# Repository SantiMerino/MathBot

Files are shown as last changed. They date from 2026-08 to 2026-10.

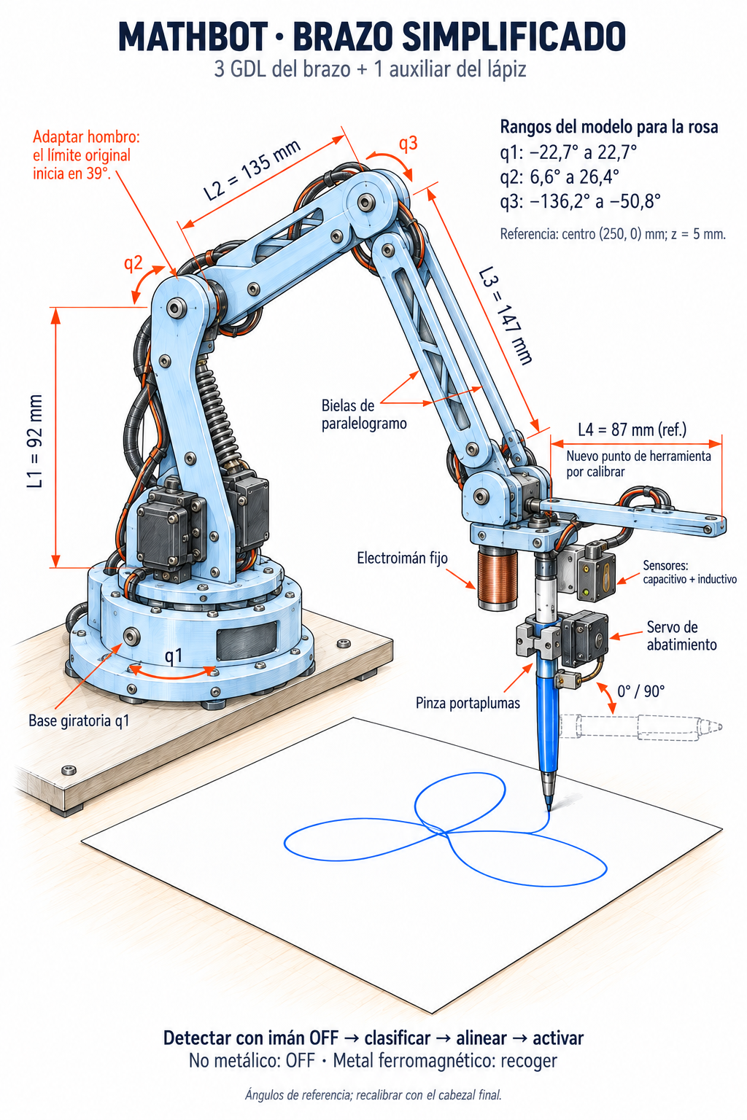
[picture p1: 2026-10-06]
Imagen de Codex 25 sept 2026, 07_56_44.png

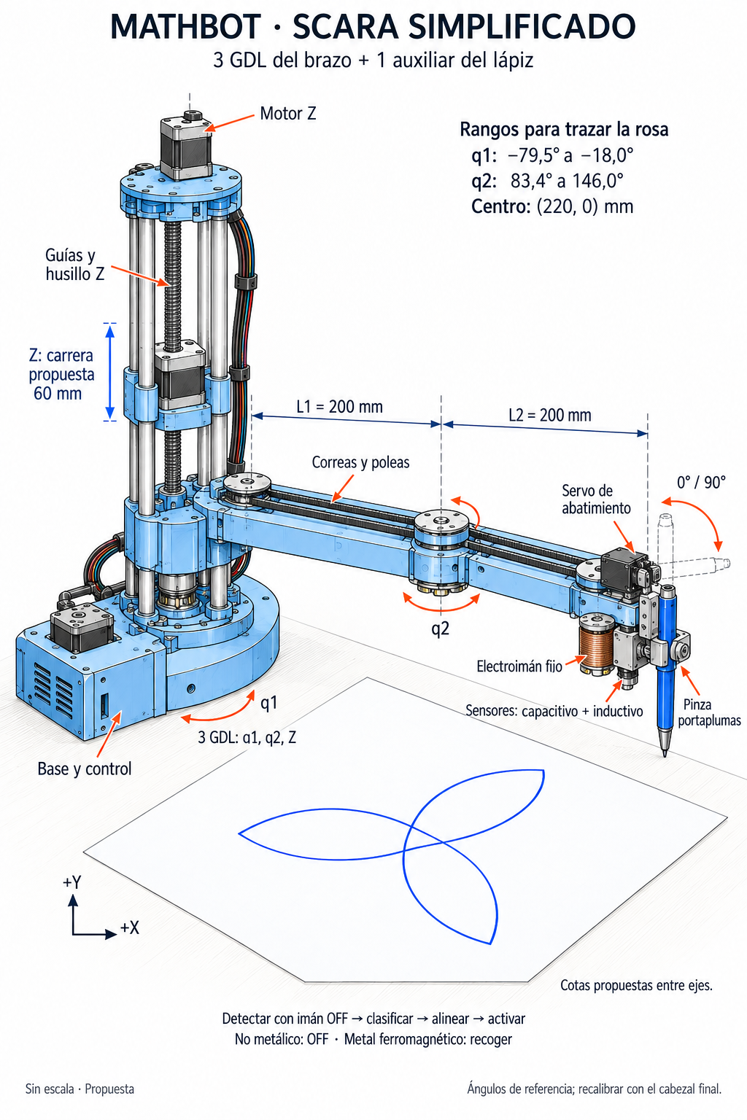
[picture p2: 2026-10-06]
Imagen de Codex 25 sept 2026, 07_56_58.png

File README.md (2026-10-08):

# MathBot

Brazo robótico de doble efector final — diseño, modelado y control de trayectorias matemáticas.

Proyecto de Aprendizaje Basado en Proyectos (PBL) que integra **Física Aplicada III** (20% del curso) y **Matemática Multivariable y Ecuaciones Diferenciales / Cálculo III** (15% del curso), semestre 2 de 2026.

---

## Pregunta retadora

> ¿Cómo podemos diseñar un brazo robótico de bajo costo capaz de manipular objetos mediante una pinza mecánica y un electroimán intercambiable, utilizando modelos matemáticos para generar y optimizar trayectorias que alcancen una precisión mínima del 90%?

## Descripción general

MATHBOT integra ambos cursos alrededor de un mismo producto físico: un brazo robótico de doble efector final, controlado por computador, capaz de ejecutar trayectorias matemáticas y realizar tareas de detección, recolección y manipulación de objetos.

A cada equipo se le entrega una **trayectoria física de referencia** construida en cartón (disponible en el SPARK). La primera tarea es observar y medir ese trazo, identificar sus características geométricas, y proponer y justificar una ecuación paramétrica —con dominio, orientación y escala— que la represente. El modelo se valida en MATLAB y, más adelante, se integra a una simulación 3D en Simulink del brazo real construido por el equipo.

---

## Nuestra trayectoria: rosa de tres pétalos

La referencia física asignada a este equipo es una **rosa de tres pétalos** con dos pétalos grandes (cuadrantes 1 y 4) y uno pequeño (eje X negativo).

### Ecuación paramétrica

$$x(t) = -A\cos(3t)\cos(t) \qquad y(t) = -A\,k\cos(3t)\sin(t) \qquad t \in [0,\pi]$$

con **A = 10.29 cm** y **k = 1.355**.

El parámetro `k` no es un ajuste arbitrario: la referencia física, tal como fue medida, parecía tener dos amplitudes distintas (13 cm en los pétalos grandes, 10 cm en el pequeño). Al medir directamente los píxeles del PDF de referencia, los tres pétalos resultaron **geométricamente idénticos** (682/680/680 px) — la asimetría aparente viene de que el documento coloca la imagen con una matriz de escala anisótropa (`sy/sx = 1.364`, confirmado por ajuste de mínimos cuadrados en `k = 1.355`). Es decir: **una sola ecuación con estiramiento en Y**, sin necesidad de una función definida por tramos.

> **Pendiente de validación física:** este modelo asume que el cartón del SPARK se imprimió a partir de ese PDF sin alteración de escala. Falta medir el trazo físico directamente y confirmar la razón pétalo-vertical / pétalo-horizontal ≈ 1.28.

### Discretización para el robot

La ejecución del brazo requiere convertir la curva continua en una lista finita de *waypoints*. El número de puntos se eligió por presupuesto de error, no de forma arbitraria:

- El objetivo de precisión del PBL es del 90% del **sistema completo**, no solo del modelo matemático. Fuentes de error ya presentes en un brazo de bajo costo: zona muerta del servo (4–9 mm), backlash de engranajes (2–5 mm), flexión de eslabones (1–4 mm), calibración del origen (2–5 mm).
- La discretización debe ser el término despreciable de esa suma → objetivo práctico: error de trazo **< 1 mm**.
- Con espaciado **adaptativo por curvatura** (más puntos donde el pétalo es más cerrado, cerca de la punta), **15 puntos por pétalo** (42 en la ruta completa) dan una desviación máxima de 0.56 mm respecto a la curva real — muy por debajo del presupuesto.

| Puntos/pétalo | Uniforme en t | Adaptativo |
|---|---|---|
| 10 | 2.14 mm | 1.37 mm |
| 12 | 1.43 mm | 0.91 mm |
| **15** | 0.93 mm | **0.56 mm** |
| 20 | 0.49 mm | 0.30 mm |

**Advertencia de implementación:** esta tabla asume que el robot interpola en línea recta entre waypoints en el plano X–Y. Si el control mueve los servos linealmente en *espacio articular* (ángulo a ángulo) en vez de cinemática inversa punto a punto, el camino cartesiano real se arquea entre waypoints y el error sube — en ese caso duplicar a 24–30 puntos por pétalo.

---

## Estructura del repositorio

```
MathBot/
├── README.md
├── docs/
│   └── MATHBOT_-_Semestre_2_2026.pdf     # enunciado oficial del PBL
├── modelo/
│   └── mathbot_trayectoria.html           # herramienta interactiva: modelo, error, export CSV/MATLAB/Arduino
├── mathbot_investigacion_construccion.html # investigación: arquitecturas, presupuesto de error, BOM y costos
├── mathbot_compras_el_salvador.html        # abastecimiento 100% local: tiendas, sustituciones, BOM en El Salvador
├── matlab/                                # simulación y validación (Avance 1 y 2)
└── firmware/                              # Arduino MEGA: firmware, pruebas, diagrama y Wokwi (ver firmware/README.md)
```

---

## Cómo se construye el brazo

`mathbot_investigacion_construccion.html` compara seis arquitecturas candidatas (antropomórfico,
SCARA, cartesiana/CNC, polar, delta y kit comercial) contra los requisitos del PBL, con presupuesto
de error, lista de materiales y costos.

**Conclusión:** SCARA de sobremesa de 3 GDL con cabezal de doble efector, eslabones `L₁ = L₂ = 20 cm`
y base a `D = 22 cm` del centro de la rosa. Con esa geometría, `θ₂` recorre solo el rango
`[72°, 126°]` en toda la trayectoria — lejos de ambas singularidades — y el número de condición
del jacobiano se mantiene por debajo de 3.5.

El hallazgo que decide el diseño no es geométrico sino de actuación: sobre esta configuración,
**1° de error articular se amplifica hasta 8.70 mm de error de trazo**. La zona muerta de un MG996R
es de 1–2°, así que en accionamiento directo el error de servo por sí solo consume todo el
presupuesto. La corrección es servo de bus serie con encóder (Feetech STS3215, 0.088° por cuenta →
0.77 mm) o reducción mecánica sobre servos analógicos.

| Ruta | Error de trazo | Costo total | Semanas |
|---|---|---|---|
| Económica — MG996R + reducción 3:1 | 4–6 mm | USD 175 | 5–6 |
| **Recomendada — SCARA + STS3215** | **≈ 2 mm** | **USD 305** | **7–9** |
| Alta precisión — NEMA 17 + AS5600 | 0.3 mm | USD 430 | 10–12 |

### Abastecimiento en El Salvador

`mathbot_compras_el_salvador.html` levanta el mapa de compras local (tiendas con dirección y
teléfono, qué comprar en cada una) y un árbol de decisión de cuatro rutas para el actuador, porque
no está confirmado qué hay realmente en el mostrador de Casa Rivas o Creativo 3D fuera de lo que
publican en línea.

| Ruta | Condición | Error | Precisión | Costo |
|---|---|---|---|---|
| A · servo de bus serie (STS3215) | si lo encuentran en stock | 1.99 mm | 98.5% | por cotizar |
| B · NEMA 17 + cabrestante 4:1 | si no hay bus serie pero sí stepper | 1.97 mm | 98.5% | ~243 USD |
| C · servo hobby + cabrestante | si no hay stepper pero sí cable de acero | 6.05 mm | 95.4% | 225 USD |
| D · servo hobby + engranes impresos | piso absoluto, cero compras extra | 6.65 mm | 94.9% | ~219 USD |

Las cuatro aprueban el 90% exigido. El hallazgo que no esperaba: con microstepping y una reducción
bien elegida, un NEMA 17 de mostrador (Ruta B) empata en precisión con un servo de bus serie que
cuesta el triple (Ruta A). La brecha real está entre {A, B} y {C, D}, no entre "importado" y
"local". Vale la pena llamar a Creativo 3D antes de resignarse a la Ruta C.

Los sensores y el electroimán sí tienen recomendación firme en cualquier ruta: fabricarlos en vez
de comprarlos. Un inductivo/capacitivo industrial local cuesta 25–60 USD cada uno; bobinarlos
cuesta ~5 USD y convierte el entregable de Física III en física medible, no en una hoja de datos.

La CNC (opción C del documento de construcción) sigue descartada: depende justo de la categoría
de piezas sin venta local confirmada. El brazo antropomórfico (opción A) sí es 100% local y usa la
misma canasta de compras que el SCARA, pero con servos directos el error va de 10 a 20 mm, rozando
el umbral.

---

## Simulación del SCARA de referencia (HowToMechatronics)

El diseño final toma como base el [SCARA de HowToMechatronics](https://howtomechatronics.com/projects/scara-robot-how-to-build-your-own-arduino-based-robot/)
(STL en `BRAZO SCARA/`). Medido en las STL: `L1 = 228 mm`, `L2 = 144 mm` (el código Arduino original
usa 136.5). J3 reduce 90/20 = 4.5:1. La pinza se reemplaza por uno de dos cabezales:

- **A · Disco tri-herramienta:** plumón a 55 mm hacia adelante (con J3 fijo actúa como un brazo 2 de
  199 mm), electroimán y sensor a 45 mm y ±120°; J3 gira para cambiar de herramienta. Varillas Z ≥ 240 mm
  (220 mm si J2 usa el NEMA 17 corto de 24 mm): el motor de J2 es lo que choca con la Top cover arriba.
- **B · Revólver triangular:** prisma 60 mm delante de J3 que un servo de 270° gira −120°/0°/+120° para
  dejar una cara hacia la hoja. Sin NEMA extra ni servo de levante, pero ≈90 g más y varillas Z ≥ 310 mm.

La rosa va centrada a 185 mm de J1, girada 180°: θ₂ ∈ [−140°, −96°], κ(J) ≤ 2.3, 0.19 mm por micropaso.
Qué imprimir y qué comprar para cada cabezal: [simulador_scara/CABEZALES_compras.md](simulador_scara/CABEZALES_compras.md).

- `simulador_scara/simulador_scara.html`: simulador 3D interactivo con las STL reales (abrir con doble
  clic; necesita internet para Three.js). Misión completa: escaneo con sensor → recolección con
  electroimán → trazo de la rosa, con cambio de cabezal A/B. Electrónica del artículo ubicada dentro
  de las piezas (motores, poleas, correas, rodamientos, Arduino + CNC Shield + A4988, finales de carrera),
  modo Rayos X e identificación de cada pieza con el cursor usando los nombres de HowToMechatronics.
  Se regenera con `python python/construir_simulador_scara.py` tras editar `plantilla.html`.
- `presupuesto/MathBot_Presupuesto_SCARA.xlsx`: presupuesto del robot con el cabezal de disco: lista de materiales con
  precios locales y de Amazon puestos en El Salvador, estado de compra, registro de gastos por integrante e impresión 3D.
  Se regenera con `python presupuesto/construir_presupuesto.py`.
- `presupuesto/rodamientos_scara.svg`: los 18 rodamientos (medidas, cantidad y dónde va cada uno), cotejados con el
  ensamble de HowToMechatronics. La lista de compras del artículo pide menos 51107/51108 y omite los radiales 6807/6806.
- `python/simular_scara.py [--gif] [--varilla 220]`: figuras para el informe (`python/figuras/scara_*.png`)
  y CSV con ángulos y pasos de motor por muestra.

---

## Cronograma de entregables — Cálculo III (15%)

| Entregable | Semana | Peso | Qué se evalúa |
|---|---|---|---|
| Avance 1 — Trayectoria paramétrica | 4 | 7% | Estimación/modelado, dominio y orientación, coherencia geométrica, justificación matemática, visualización en MATLAB, validación inicial contra la referencia física |
| Avance 2 — Optimización y simulación 3D | 12 | 3% | Actualización del modelo con restricciones de ingeniería, implementación en MATLAB/Simulink, simulación 3D del brazo real, informe técnico breve |
| Entrega final — Validación y defensa | 17 | 5% | Coherencia modelo–simulación–movimiento real, cuantificación y análisis del error, conclusiones, defensa oral |

## Cronograma de entregables — Física Aplicada III (20%)

| Entregable | Peso | Qué se evalúa |
|---|---|---|
| I. Propuesta conceptual y funcional básica | 5% | Bitácora de alternativas de materiales, arquitectura de control, grados de libertad, control individual y verificable de cada servomotor y del sensor de material |
| II. Control automático del robot | 15% | Ciclos estructurados de prueba, medición, análisis y ajuste; optimización del sistema físico y de control |

## Separación de evidencias por curso

| Evidencia | Curso | Enfoque |
|---|---|---|
| Ecuación paramétrica del trazo físico | Cálculo III | Modelado, justificación, dominio, orientación, visualización |
| Simulación 3D en Simulink | Cálculo III | Correspondencia geometría del prototipo ↔ modelo ↔ ejecución |
| Optimización y análisis de sensibilidad | Cálculo III | Herramientas de cálculo multivariable, restricciones, argumentación |
| Modelo con ecuaciones diferenciales | Cálculo III | Formulación, solución/interpretación, comportamiento dinámico |
| Estructura mecánica, servos, efectores | Física III | Diseño físico, viabilidad, carga, decisiones de ingeniería |
| Sensor de material, electroimán, circuitos | Física III | Principios eléctricos/magnéticos, pruebas, desempeño |
| Precisión final del recorrido | Ambas | Cálculo III: fidelidad matemática y error de trayectoria · Física III: desempeño físico y control |

---

## Requisitos funcionales del robot (Física III)

- Doble efector final: pinza mecánica + electroimán intercambiable.
- Sensor capaz de distinguir el tipo de material entre dos objetos desconocidos.
- Debe tomar únicamente el objeto **metálico de ~70 g** y desplazarlo por la trayectoria definida.
- Control individual y verificable de cada servomotor.

## Pendientes abiertos

- [ ] Medir el trazo físico en cartón (SPARK) y confirmar `k ≈ 1.355` contra la referencia real.
- [ ] Definir explícitamente el criterio de error (% del radio máximo, del radio local, o de la longitud de arco) para el reporte del 90% de precisión. *Propuesta en la investigación: `e_RMS ≤ 10% · R_max = 13.2 mm` como criterio oficial y `e_max < 3 mm` como meta interna. El criterio de radio local es inviable: la rosa pasa por el origen y la tolerancia se anula.*
- [ ] Decidir interpolación cartesiana vs. articular en el firmware, y ajustar el número de waypoints en consecuencia. *Propuesta: cartesiana — los servos de bus serie aceptan >50 Hz, suficiente para resolver la IK en línea.*
- [ ] Confirmar con el docente si el objeto metálico de 70 g es ferromagnético. Si es aluminio o cobre, el electroimán no lo levanta aunque el sensor inductivo sí lo detecte.
- [ ] Construir la simulación 3D en Simulink con la geometría real del prototipo (Avance 2).
- [ ] Documentar el diseño mecánico: grados de libertad, actuadores, arquitectura de control.

---

*Documento fuente: `MATHBOT_-_Semestre_2_2026.pdf`, enunciado oficial del PBL.*

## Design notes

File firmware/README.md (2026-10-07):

# Firmware MathBot · Arduino MEGA 2560

Diagrama de conexión

La CNC Shield V3 se monta sobre el Mega igual que sobre el UNO: los pines D2–D13 y A0–A3 coinciden,
así que motores y finales de carrera quedan como en el artículo de HowToMechatronics. Lo que agrega
el cabezal de disco va a los pines que solo tiene el Mega.

| Función | Pin | Notas |
|---|---|---|
| J1 · J2 · J3 · Z (STEP / DIR) | 2/5 · 3/6 · 4/7 · 12/13 | ranuras X, Y, Z, A (eje A clonado en D12/D13) |
| Enable de los 4 drivers | D8 | LOW = energizados |
| Finales SW1 J1 · SW2 J2 · SW3 J3 · SW4 Z | D11 · D10 · D9 · A3 | NC a GND, como HTM |
| Sensor inductivo (vía PC817) | D22 | LOW = metal |
| Electroimán (módulo MOSFET D4184) | D24 | diodo 1N5819 en paralelo a la bobina |
| START · PARO | D26 · D28 | NA a GND · hongo NC a GND |
| LED verde · amarillo · rojo | D30 · D32 · D34 | con 220 Ω |
| Buzzer | D36 | |
| Servo SG90 del plumón | D44 | alimentado por el buck a 5.5–6 V, no por el Mega |
| Monitor de 12 V | A8 | divisor 10 kΩ / 3.3 kΩ |
| Libres | Serial1–3, I2C 20/21, A9–A15, impares D23–D53 | HC-05, STS3215, AS5600, LCD |

Microstepping: jumper **solo en MS2** de cada driver (1/4 de paso, el que usa `python/scara_modelo.py`).

## Sketches

| Carpeta | Para qué |
|---|---|
| `mathbot_mega/` | Firmware completo: homing, IK por herramienta, cambio de herramienta con J3, misión (escaneo → recolección → rosa), paro de emergencia y comandos por Serial |
| `prueba_componentes/` | Menú para probar cada motor, final de carrera, sensor, electroimán, botones, LED, buzzer y los 12 V por separado |
| `prueba_servo/` | Calibra las posiciones ARRIBA/ABAJO del plumón; copia los valores a `SERVO_ARRIBA` / `SERVO_ABAJO` |

Necesitan la biblioteca **AccelStepper** (Gestor de bibliotecas). Placa: *Arduino Mega or Mega 2560*.
Monitor Serie a 115200 con fin de línea "Nueva línea".

Orden recomendado: `prueba_servo` → `prueba_componentes` (ajusta `INVERTIR_DIR` si un eje gira al revés)
→ `mathbot_mega` con `H` y luego `R`. Antes de la primera misión calibra `HOME_POS` (están los valores
de HTM) y las alturas Z.

## Simular en Wokwi

1. Abre <https://wokwi.com/projects/new/arduino-mega>.
2. Pestaña `diagram.json`: reemplaza todo por `wokwi/diagram.json`.
3. Library Manager → agrega **AccelStepper** (o crea `libraries.txt` con el de `wokwi/`).
4. Pestaña `sketch.ino`: pega el sketch que quieras probar y cambia `SIMULACION = true`
   (en Wokwi los finales de carrera son pulsadores NA).
5. Play. Comandos útiles en `mathbot_mega`: `S` (salta el homing), `?`, `T s`, `M 200 -100`, `D`, `R`.
   Para probar el homing con `H`, pulsa SW4, SW3, SW2 y SW1 en ese orden mientras cada motor gira.

En la simulación el electroimán es el LED morado, el sensor es el pulsador azul "Sensor: metal"
(mantenlo apretado durante el escaneo para marcar una pieza como metálica), el PARO es el interruptor
deslizante y el potenciómetro hace de divisor de 12 V. El servo se alimenta del 5 V solo en Wokwi.

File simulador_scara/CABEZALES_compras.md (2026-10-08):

# Cabezales MathBot: qué imprimir y qué comprar

Supuesto de materiales para los dos efectores que reemplazan la pinza del SCARA de HowToMechatronics.
El resto del robot (base, columna Z, brazos, poleas, NEMA 17, A4988, CNC Shield) se mantiene como en el artículo; el Arduino UNO se cambia por un MEGA 2560 (ver `firmware/README.md`).
Precios de referencia en USD (AliExpress / tiendas de electrónica); hay que confirmarlos en El Salvador.

## Comparación rápida

| | A · Disco tri-herramienta | B · Revólver triangular |
|---|---|---|
| Cómo cambia de herramienta | J3 gira ±120° | Servo de 270° gira el prisma −120° / 0° / +120° |
| Dónde queda la punta activa | 55 mm (plumón) / 45 mm del eje J3 | 60 mm delante de J3, en la línea del brazo 2 |
| Levante del plumón | Micro-servo SG90 (obligatorio) | No hace falta: el plumón sube con Z |
| Masa estimada | ≈ 150 g | ≈ 240 g |
| Varillas Z mínimas (NEMA de J2 estándar / corto 24 mm) | 240 / 220 mm | 310 / 300 mm |
| Principal fuente de error propia | Juego de la correa de J3 (≈0.5°) × 55 mm ≈ 0.5 mm | Zona muerta del servo (≈1°) × 85 mm ≈ 1.5 mm; con enclavamiento ≈ 0.2–0.3 mm |
| Tiempo de la misión simulada | 86 s | 101 s |

Ambos cumplen los tres requisitos (sensor de metales, electroimán y plumón/lápiz). La pinza original (servo MG996R + piezas) pesa unos 130–150 g, así que A queda igual y B suma unos 100 g.

## A · Disco tri-herramienta

**Imprimir** (≈ 50 g, ≈ 4.5 h)

| Pieza | Material | g | h |
|---|---|---:|---:|
| Placa-disco Ø136 × 6 mm (aligerada), 4 M4 al *Gripper to J3 connector* | PLA+/PETG, 3 perímetros, 30 % | 30 | 2.5 |
| Porta-plumón con camisa deslizante y resorte | PETG | 8 | 0.8 |
| Leva + soporte del micro-servo | PLA+ | 5 | 0.5 |
| Separador del electroimán (25 mm) | PLA+ o varilla M4 | 3 | 0.3 |
| Abrazadera M12 del sensor | PLA+ | 4 | 0.4 |

**Comprar**

| Componente | Cant. | USD | g |
|---|---:|---:|---:|
| Electroimán 12 V KK-P20/15 (Ø20 × 15, ≈2.5 kgf) | 1 | 3–5 | 32 |
| Sensor inductivo LJ12A3-4-Z/BX (M12, NPN NA, 4 mm) | 1 | 3–6 | 30 |
| Micro servo SG90 (o MG90S metálico) | 1 | 2–4 | 10 |
| Plumón Sharpie fino (o lápiz) | 1 | 1–2 | 11 |
| Resorte de compresión Ø10–12 × 20 mm | 1 | <1 | 1 |
| Tornillería M3/M4 + tuercas de seguridad | — | 2 | 10 |

## B · Revólver triangular

Prisma triangular en voladizo, 60 mm delante de J3 y con el eje a lo largo del brazo 2. La cara activa queda paralela a la hoja.
El voladizo no es un capricho: con 3 herramientas a 120° y un giro de 240°, dos de ellas pasan apuntando hacia arriba. Si el prisma colgara justo bajo J3, el sensor chocaría con el acople de J3. Por eso el plumón (la herramienta más larga) va en la posición central del servo y nunca apunta hacia arriba.

**Imprimir** (≈ 83 g, ≈ 8 h)

| Pieza | Material | g | h |
|---|---|---:|---:|
| Soporte en L (brida → 60 mm adelante) con mejilla para servo y rodamiento | PETG, 4 perímetros, 40 % | 30 | 3 |
| Prisma triangular hueco (lado 62 mm, largo 40 mm, eje Ø5) | PLA+/PETG, 30 % | 32 | 3 |
| Porta-plumón con resorte (cara 0°) | PETG | 8 | 0.8 |
| Base del electroimán (cara −120°) y boss M12 del sensor (cara +120°) | PLA+ | 7 | 0.7 |
| Acople horn del servo → prisma | PETG | 3 | 0.3 |
| Leva de 3 muescas (enclavamiento) | PETG | 3 | 0.3 |

**Comprar**

| Componente | Cant. | USD | g |
|---|---:|---:|---:|
| Servo 270° metálico DS3218MG (20 kg·cm), o MG996R + engranes impresos 2:3 | 1 | 10–15 | 60 |
| Rodamiento 625ZZ (5 × 16 × 5) + perno M5 × 50 | 1 | 1–2 | 8 |
| Émbolo de bola con resorte M6/M8 (o bola Ø5 + resorte) | 1 | 2–4 | 5 |
| Electroimán 12 V KK-P20/15 | 1 | 3–5 | 32 |
| Sensor inductivo LJ12A3-4-Z/BX | 1 | 3–6 | 30 |
| Sharpie Mini (o lápiz recortado ≈70 mm) | 1 | 1–2 | 7 |
| Resorte de compresión Ø10–12 × 20 mm | 1 | <1 | 1 |
| Tornillería M3/M4/M5 | — | 2 | 12 |

Par necesario: menos de 1 kg·cm (desbalance de herramientas + arrastre del plumón, 0.5 N × 85 mm). Cualquier servo de 270° alcanza; se pide uno metálico por rigidez y para reducir la zona muerta. No se usa otro NEMA.

## Electrónica común (A y B)

| Componente | Cant. | USD | Conexión |
|---|---:|---:|---|
| Módulo MOSFET de nivel lógico D4184 (o IRLZ44N) + diodo 1N5819 | 1 | 1–2 | electroimán → D24 |
| Optoacoplador PC817 (o divisor 10 kΩ / 4.7 kΩ) | 1 | 1 | sensor de 12 V → D22 |
| Convertidor buck 12 → 6 V: LM2596 (A) o XL4015 5 A (B) | 1 | 2–5 | alimenta el servo; señal en D44 |
| Cable flexible de 6–8 hilos AWG 24–26 (silicona), 1.5 m | 1 | 3–5 | pasa por los ejes huecos de J2 y J3 |
| Conectores JST-XH / Dupont y termorretráctil | — | 2 | — |

- Con el MEGA 2560 el cabezal usa pines que no toca la CNC Shield: **D22** sensor, **D24** electroimán y **D44** servo. Los finales de carrera siguen en D9, D10, D11 y A3, como en HTM.
- Diagrama completo y firmware en [`firmware/`](../firmware/README.md).
- **Fuente:** la de 12 V 6 A del artículo alcanza si el servo solo se mueve con los steppers quietos, como en la simulación.

El simulador (`simulador_scara.html`) muestra estas mismas tablas para el cabezal seleccionado.

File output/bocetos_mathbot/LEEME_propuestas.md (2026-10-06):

# MathBot: dos propuestas conceptuales
Fecha: 24 de septiembre de 2026.

Láminas elaboradas con image_gen integrado: propuesta_01_scara.png y propuesta_02_eezy.png. Los prompts y ajustes se conservan en prompts.md. Son bocetos de propuesta con despiece y BOM por conjuntos, sin escala ni tolerancias de fabricación. Las dimensiones del modelo y las dimensiones propuestas se distinguen a continuación.

## Requisitos y decisiones de diseño
Del enunciado MATHBOT_-_Semestre_2_2026.pdf: pinza mecánica y electroimán intercambiables, detección de material entre dos objetos desconocidos, selección únicamente del objeto metálico de aproximadamente 70 g, trayectoria matemática, control por computador/Arduino, control verificable de servomotores, sensor capacitivo, simulación del brazo real y objetivo de precisión mínima de 90%.

Solicitud adicional del usuario: dos bocetos, aspecto de lápiz/plano, identificación de piezas y cabezal modular automático con electroimán, sensor y Sharpie o lápiz. Se mantiene la pinza exigida por el proyecto.

Decisiones de estas propuestas: añadir detección inductiva complementaria al sensor capacitivo; bloqueo mecánico verificable; portaplumas con resorte; servos con encoder como candidatos. No son requisitos añadidos al enunciado ni selecciones comerciales definitivas. El sensor capacitivo se conserva en AMBAS propuestas aunque alguna anotación abreviada de la ilustración EEZY lo describa como opcional.

El sensor inductivo identifica presencia de metal bajo condiciones calibradas; no identifica por sí solo el tipo exacto de aleación. El electroimán requiere una pieza ferromagnética. Si el objeto metálico no es atraído, la pinza permite tomarlo después de la detección; no se debe programar la recolección del objeto no metálico. El sensor de bloqueo tiene otra función: verificar el acople o la posición del selector.

## Propuesta 01: SCARA con estación de intercambio
Inspiración mecánica: SCARA de HowToMechatronics. Conserva torre, guías verticales, husillo, carro y dos eslabones horizontales articulados. Adaptación: 2 rotaciones en XY y traslación Z; el cabezal reemplaza la garra original. Se proponen servos con encoder en las dos rotaciones, correas dentadas y motor de pasos en Z. La selección final de actuadores y sus transmisiones requiere cálculo de carga.

Geometría de partida de la investigación local: L1 = L2 = 200 mm y centro de rosa a D = 220 mm del eje de base. Son cotas propuestas de MathBot, no medidas copiadas del robot publicado. Longitudes de guías, recorrido Z, altura de papel y posición del almacén quedan por dimensionar.

Cambio automático: elevar; entrar en el puesto libre; apoyar el cartucho; retraer el pestillo; separar; ir a otra herramienta; centrar y acoplar; bloquear; confirmar; salir. Tres alojamientos: portaplumas, electroimán y pinza. Durante el uso de una herramienta su alojamiento queda vacío. La lámina ilustra el equipamiento de los tres puestos, no un inventario simultáneo de cartuchos.

El receptor permanece en el brazo con sensores y actuador de cierre. Cada cartucho lleva placa común, superficies de referencia, orientación mecánica y contactos eléctricos. El diseño debe descargar fuerzas en las superficies de apoyo, no en los contactos. Los contactos se energizan después de confirmar bloqueo y se desenergizan antes de liberar.

| ID | Pieza o conjunto | Cantidad preliminar | Desglose y función |
|---|---|---|---|
| 01 | Tablero de trabajo | 1 | Superficie plana, sujeción de papel y anclajes |
| 02 | Base y giro J1 | 1 conjunto | Carcasa, plato, eje y soporte de rodamientos |
| 03 | Servos con encoder | 2 | Movimiento de J1 y J2; soportes por diseñar |
| 04 | Guías verticales | 4 | Varillas y abrazaderas superior/inferior |
| 05 | Husillo T8 y tuerca | 1 conjunto | Husillo, tuerca, soporte axial |
| 06 | Motor Z y acople | 1 conjunto | Motor, soporte y acople al husillo |
| 07 | Carro y cojinetes lineales | 1 conjunto | Carro portabrazo y cojinetes correspondientes a las guías |
| 08 | Brazo 1 | 1 | Cuerpo, tapa y uniones; 200 mm entre ejes propuestos |
| 09 | Junta J2 y rodamientos | 1 conjunto | Eje, alojamiento, cojinetes y fijaciones |
| 10 | Brazo 2 | 1 | Cuerpo, tapa y soporte del receptor; 200 mm propuestos |
| 11 | Correas GT2, poleas y tensores | 2 juegos | Un juego por articulación; reducción por definir |
| 12 | Receptor y pestillo con servo | 1 conjunto | Brida, apoyo de centrado, llave antigiro, pestillo, servo, fin de carrera |
| 13 | Contactos y placas de herramienta | 1 juego | Bloque receptor de contactos y 3 placas/cartuchos compatibles |
| 14 | Sensores de material | 1 par | Sensor capacitivo y sensor inductivo auxiliar con soporte fijo |
| 15 | Portaplumas con resorte | 1 | Abrazadera, guía deslizante, resorte, tope y lápiz/Sharpie |
| 16 | Electroimán bobinado | 1 | Núcleo, bobina, carrete, aislamiento y placa |
| 17 | Pinza y microservo | 1 conjunto | 2 mordazas, transmisión, guías/ejes, servo y placa |
| 18 | Estación de tres puestos | 1 | Bastidor y 3 cunas con retención y referencias |
| 19 | Arduino, potencia y fuente | 1 conjunto | Controlador, interfaces, driver Z, reguladores y etapa del electroimán |
| 20 | Tornillos, insertos y cableado | 1 lote | Longitudes, calibres y cantidades por cerrar en CAD |

Ventaja conceptual: el brazo transporta solo el cartucho activo. Compromiso: necesita espacio para la estación y un acople repetible.

## Propuesta 02: EEZY con torreta modular
Inspiración: EEZYbotARM Mk2 y el modelo local easyEEZYbotARM. Conserva base giratoria, hombro, brazo/antebrazo y transmisión por bielas. Se propone estructura reforzada, soporte bilateral de articulaciones y compensación del peso del brazo mediante resorte.

La librería local define L1 = 92, L2 = 135, L3 = 147 y L4 = 87 mm. Son parámetros de referencia de la cadena original. El cabezal nuevo modifica la posición de la punta: L4 y el desplazamiento de cada herramienta necesitan actualización. La simulación local centra la rosa a X = 250 mm, utiliza Z = 5 mm y amplía los límites articulares del modelo; ello no demuestra contacto real con el papel ni ausencia de colisiones.

Selector automático: elevar a una zona despejada; liberar el bloqueo; girar el tambor a la siguiente estación nominal de 120 grados; bloquear y confirmar; compensar la posición de la herramienta; aproximar. Los tres cartuchos permanecen en el cabezal. Son desmontables para mantenimiento, pero la selección en servicio ocurre por giro del tambor. Un eje horizontal coloca un cartucho hacia abajo y los otros fuera del plano de trabajo. El sistema debe limitar el giro y retornar para evitar torsión acumulada del cableado.

| ID | Pieza o conjunto | Cantidad preliminar | Desglose y función |
|---|---|---|---|
| 01 | Tablero y base fija | 1 conjunto | Tablero, base y fijación |
| 02 | Plataforma giratoria J1 | 1 | Plato, apoyo y eje |
| 03 | Servos con encoder | 3 | Base, hombro y accionamiento de codo/bielas |
| 04 | Soportes de hombro | 1 par | Placas laterales con apoyo bilateral |
| 05 | Brazo superior | 1 | Eslabón y fijaciones |
| 06 | Antebrazo | 1 | Eslabón distal y fijaciones |
| 07 | Bielas de paralelogramo | 1 juego | Barras, pivotes y articulaciones de transmisión/nivelación |
| 08 | Ejes, cojinetes y separadores | 1 lote | Uniones de base, brazo y transmisión |
| 09 | Resorte de compensación | 1 | Resorte y dos anclajes; precarga por calcular |
| 10 | Portacabezal nivelado | 1 | Soporte del conjunto distal |
| 11 | Horquilla de torreta | 1 | Dos apoyos del eje y unión al portacabezal |
| 12 | Tambor y eje horizontal | 1 conjunto | Tambor de 3 estaciones, eje y dos rodamientos |
| 13 | Servo selector | 1 | Accionamiento del tambor; transmisión por dimensionar |
| 14 | Indexador, bloqueo y sensor | 1 conjunto | Disco, pasador, liberación actuada y confirmación de posición |
| 15 | Cartucho de lápiz con resorte | 1 | Placa, abrazadera, guía, resorte y herramienta |
| 16 | Cartucho de electroimán | 1 | Placa, núcleo, bobina y conexiones |
| 17 | Cartucho de pinza y microservo | 1 | Placa, mordazas, ejes/transmisión y microservo |
| 18 | Sensores capacitivo e inductivo | 1 par | Soporte fijo fuera del barrido del tambor |
| 19 | Arduino, potencia y fuente | 1 conjunto | Control, interfaces de servos/sensores y etapa de potencia |
| 20 | Tornillos, insertos y cableado | 1 lote | Incluye conectores de cartucho y lazo de cable de giro limitado |

Ventaja conceptual: selección sin estación externa. Compromiso: el brazo soporta todos los cartuchos, el tambor y su accionamiento. Los 70 g corresponden al objeto y se suman al peso completo del cabezal; no se ha validado la capacidad del EEZY modificado.

## Electrónica común y validaciones necesarias
- PC/MATLAB o Python envía trayectorias al controlador. La geometría final deberá trasladarse a Simulink conforme al enunciado.
- Alimentación de actuadores dimensionada por corrientes reales; regulación independiente para lógica/sensores según componentes elegidos.
- Electroimán controlado mediante etapa MOSFET y diodo de rueda libre; adaptar las señales de sensores a la tensión lógica.
- Comprobar bloqueo y herramienta seleccionada antes de ejecutar la trayectoria.
- Calibrar el punto de trabajo de cada herramienta y la altura del papel. La punta de escritura requiere recorrido elástico y fuerza de contacto limitada.
- Verificar par, rigidez, carga con herramienta, holgura, repetibilidad, interferencias, alcance de toda la rosa y acceso al almacén o barrido de torreta.
- Definir con el curso la métrica del 90% y medirla en el robot físico. Ni estos bocetos ni la coincidencia IK/FK prueban esa precisión.
- Tornillos e insertos aparecen como lote porque faltan CAD, espesores y tolerancias. No se trasladan automáticamente las medidas M3/M4 de la imagen original a los nuevos cabezales.

## Fuentes consultadas
- [SCARA de HowToMechatronics](https://howtomechatronics.com/projects/scara-robot-how-to-build-your-own-arduino-based-robot/): arquitectura, guías, transmisiones y montaje de referencia.
- [easyEEZYbotARM](https://github.com/meisben/easyEEZYbotARM): modelo y documentación del brazo. Sus notas de uso no acreditan una capacidad de 70 g para esta adaptación.
- [EEZYbotARM Mk2, autor original](https://www.instructables.com/EEZYbotARM-Mk2-3D-Printed-Robot/).
- Enunciado local: MATHBOT_-_Semestre_2_2026.pdf.
- README.md y mathbot_investigacion_construccion.html: trayectoria y geometría SCARA propuesta. Sus estimaciones de desempeño/costos no se consideran resultados experimentales.
- python/easyEEZYbotARM/kinematic_model.py: dimensiones originales Mk2.
- python/simular_trayectoria_eezy.py y python/figuras/eezy_poses_petalos.png: configuración y vistas de la simulación local.

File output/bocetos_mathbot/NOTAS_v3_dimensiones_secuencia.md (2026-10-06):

# MathBot v3: cabezal sencillo, dimensiones y ángulos
Fecha: 24-09-2026. Dibujos generados con ImageGen; sin escala y sin tolerancias de fabricación. Esta revisión sustituye la propuesta de torreta/cambio automático para la función solicitada. No modifica las simulaciones ni los documentos anteriores.

## Función del cabezal
Una placa fija porta el electroimán y los sensores. Una pinza sencilla de dos mitades sujeta exclusivamente el lápiz; se aprieta manualmente. Un servo auxiliar abate el portaplumas: posición nominal 0° para escribir y 90° para retirarlo. Son posiciones funcionales propuestas, no pulsos ni ángulos absolutos del servo seleccionado.

No hay almacén, cartuchos intercambiables, torreta ni apertura/cierre motorizado de la pinza. El electroimán recoge objetos; la pinza sostiene el instrumento que traza la curva. El lápiz, electroimán y sensores están lateralmente separados, nunca apilados en el mismo eje. El lápiz desplegado llega al papel antes que el imán; al abatirlo, el imán queda libre para aproximarse al objeto. El muelle/guía del portaplumas, los topes de abatimiento y su despeje deben dimensionarse con el lápiz real.

## Dimensiones y grados de libertad
| Parámetro | SCARA | Brazo EEZY |
|---|---|---|
| Primer eslabón móvil | 200 mm entre ejes | L2 = 135 mm, hombro a codo |
| Segundo eslabón móvil | 200 mm entre ejes | L3 = 147 mm, codo a muñeca |
| Desplazamiento vertical fijo | Según montaje de torre | L1 = 92 mm, referencia base a hombro del modelo |
| Desplazamiento de herramienta original | Modelo XY de dos barras | L4 = 87 mm, desplazamiento horizontal original, no longitud del lápiz |
| Eje vertical | Carrera propuesta 60 mm | Movimiento combinado de hombro/codo |
| GDL de posicionamiento | 3: q1, q2, Z | 3: q1, q2, q3 |
| Movimiento auxiliar independiente | 1: abatimiento de lápiz | 1: abatimiento de lápiz |

Por tanto, cada propuesta tiene cuatro movimientos actuados independientes contando el portaplumas. El electroimán ON/OFF no añade un grado de libertad. La pinza apretada no añade otro eje controlado. Las bielas pasivas tampoco son GDL adicionales.

Dimensiones de bielas auxiliares que figuran en la librería EEZY: L2A = 60 mm, LAB = 140 mm y LB3 = 60 mm. Son parámetros de su mecanismo original, no cotas de cualquier barra visualmente parecida del boceto. Conservar su conectividad y validar nivelación en CAD. Las láminas solo acotan la cadena principal para mantener legibilidad.

## Ángulos: cálculo, convenciones y alcance
Se evaluaron 20 001 muestras de:
x_r = -102.9 cos(3t) cos(t), y_r = -102.9 × 1.3552 cos(3t) sin(t), t de 0 a pi.
Todas las longitudes se expresan en mm. La rosa tiene un pétalo hacia -X.

| Articulación | SCARA: centro (220,0) | EEZY original: centro (250,0), z=5 |
|---|---:|---:|
| q1 | -79.467° a -17.963° | -22.696° a 22.696° |
| q2 | 83.419° a 145.955° | 6.577° a 26.388° |
| q3 | No aplica | -136.213° a -50.766° |

Estos son intervalos articulares requeridos por la curva del MODELO DE REFERENCIA, no límites garantizados del mecanismo ni recorridos de servomotores. La ilustración es una vista de conjunto, no una pose numérica determinada.

SCARA: q1 se mide desde +X hacia el primer eslabón; q2 es el giro relativo del segundo respecto al primero. Se utiliza la rama q2 positiva. La orientación completa de la placa distal cambia con q1+q2, por lo que el desplazamiento lateral entre lápiz, sensor e imán debe rotarse al compensarlo.

EEZY: q1 es el giro de base desde +X; q2, la elevación del primer eslabón móvil desde la horizontal; q3, el giro relativo del codo. La elevación absoluta del antebrazo es q2+q3. Los ángulos del modelo no equivalen directamente a los comandos de servo: la librería los transforma mediante calibración y geometría de bielas.

El cálculo reproduce la cinemática directa con error numérico inferior a 1e-8 mm. Esto solo verifica las ecuaciones, no la precisión del robot.

### Diferencia con cifras previas del SCARA
El rango de codo 72° a 126° del documento anterior corresponde al alejamiento del pétalo pequeño respecto a la base, una orientación diferente de la usada aquí. Con la ecuación negativa del README y el centro en (220,0), el rango correcto es 83.4° a 146.0°. Cambiar orientación o ubicación de la curva exige recalcular ambos ángulos.

### Restricción real del EEZY
El modelo original establece q1 entre -30° y 30°, q2 entre 39° y 120°, y límites de q3 dependientes de q2:
q3_min = -0.6755 q2 - 70.768;
q3_max = -0.7165 q2 - 13.144.
La trayectoria actual requiere q2 inferior a 39° en todas las muestras: no cabe en esos límites originales.

La simulación local amplía q2 a 0°–120° y q3 a -160°–-20°. Ampliar esos números no modifica los topes físicos ni demuestra ausencia de colisión. El EEZY requiere adaptar montaje/geometría o reubicar el plano de dibujo y volver a calcular la trayectoria.

El nuevo cabezal introduce desplazamientos horizontales y verticales distintos para lápiz, sensor e imán; L4=87 mm y z=5 mm son referencias del modelo anterior. En particular, z=5 mm no representa automáticamente contacto real con el papel. Hay que medir las tres posiciones de trabajo y actualizar la cinemática antes de usar los rangos como diseño definitivo.

## Secuencia de detección y recogida
1. Elevar el cabezal y abatir el lápiz a la posición retirada; mantener el imán apagado.
2. Situar los sensores frente al objeto a la distancia de detección calibrada, con sus campos despejados del imán y la estructura.
3. Confirmar presencia mediante el capacitivo y comprobar respuesta del inductivo. Solo clasificar tras lecturas estables en una región y distancia donde ambos sensores hayan sido caracterizados.
4. Si hay presencia y no respuesta inductiva, clasificar provisionalmente como no metálico dentro de esa calibración y no activar el imán. Si no se confirma presencia, repetir aproximación; una lectura negativa sola no prueba material no metálico.
5. Si se confirma metal, guardar la clasificación, elevar y desplazar la herramienta para alinear el electroimán sobre el mismo objeto. Compensar la separación física sensor–imán con la orientación actual del brazo.
6. Bajar, activar el imán mediante etapa de potencia y realizar una elevación corta de comprobación. Solo transportar si se verifica recogida; la detección inductiva no confirma por sí misma que la pieza quedó sujeta.
7. Depositar y desactivar. Antes de otra detección, esperar la estabilización del sistema y volver a leer con el imán apagado.
8. Para dibujar: imán apagado, desplegar lápiz, ajustar contacto y ejecutar la rosa.

El capacitivo detecta tanto materiales metálicos como no metálicos; no garantiza clasificación de objetos desconocidos por sí solo. Se propone el inductivo como complemento. La clasificación depende de tamaño, distancia y material, y requiere ensayos con las piezas reales.

Un metal detectado puede no ser ferromagnético: aluminio/cobre pueden detectarse pero no levantarse con este electroimán. La secuencia de recogida presupone una pieza ferromagnética; ante falta de sujeción, detener/rechazar, sin utilizar la pinza del lápiz como garra. El sensor y el imán funcionan en una misma secuencia, sin exigir detección fiable mientras el imán está energizado.

## Pendientes de dimensionamiento
- Masa completa del cabezal más objeto de unos 70 g, par de cada articulación, retención magnética real y calentamiento de bobina.
- Soporte del servo de abatimiento con tope mecánico para que el juego del servo no determine por sí solo la posición de escritura.
- Calibración y montaje de sensores para evitar detectar permanentemente el propio núcleo, tornillos o soporte.
- Transistores/driver, protección de carga inductiva y alimentación compatibles con bobina y sensores.
- Recorridos físicos con margen, altura de objetos, evitación de colisiones y postura para abatir el lápiz.
- Criterio de precisión del 90% y ensayo experimental. No se acredita con este boceto.

## Archivos y fuentes
- scara_vertical_cotas_v3.png y brazo_vertical_cotas_v3.png: láminas finales.
- verificar_angulos_v3.py y angulos_referencia_v3.json: cálculo reproducible y resultados.
- prompts_v3_dimensiones.md: prompts de generación y correcciones.
- python/easyEEZYbotARM/kinematic_model.py: cotas, límites y convenciones originales.
- python/simular_trayectoria_eezy.py: curva, centro, altura y límites ampliados.
- README.md y mathbot_investigacion_construccion.html: geometría propuesta y requisitos.
- [ifm: sensores capacitivos y diferencia con inductivos](https://www.ifm.com/us/en/category/200_010_030).
- [ifm: alcance y respuesta de sensores inductivos](https://www.ifm.com/us/en/us/overview/inductive/technology-overview/tech-overview).

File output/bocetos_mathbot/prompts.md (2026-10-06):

# Prompts finales

## Ajuste de la segunda lámina: torreta y numeración

Edit this existing MathBot EEZY technical proposal sheet. Preserve the pencil/blue/orange style, title, main EEZY robot body and linkage, reference dimensions, overall layout, sensor pair, and 3-petal curve. Correct the turret depiction and replace the corrupted bottom BOM strip. This is a mechanical-clarity correction, not a redesign.
1. In both main robot's head and enlarged operational head, render a drum rotating on a HORIZONTAL axle, with exactly THREE tool cartridges attached RADIALLY 120 degrees apart in the same rotational plane. The active pen cartridge projects straight DOWN from the bottom radial face. The magnet cartridge projects UP-LEFT from another radial face with its pole face pointing up-left. The gripper cartridge projects UP-RIGHT from the third radial face with jaws pointing up-right. Thus only the pen can touch the paper; the tools are not all hanging parallel vertically. Draw radial support mounts explicitly. Keep fixed two-sensor bracket on stationary outer yoke pointing down, separated from rotating envelope. Horizontal-axis motor drive and bearings connect to side of drum, not a top vertical spindle. Exploded detail corresponds to this same architecture, with three cartridges shown around drum radially using dashed assembly arrows, not stacked inline on shaft. Tool pose clarity is the most important visual change.
2. Replace entire bottom illustrated BOM strip with a CLEAN LEGIBLE TABLE of 20 exact rows split into 2 column groups (01–10 left, 11–20 right). No duplicate IDs. Table contents verbatim:
01 Tablero y base fija | 1 conj.
02 Plataforma giratoria J1 | 1
03 Servos con encoder | 3
04 Soportes de hombro | 1 par
05 Brazo superior | 1
06 Antebrazo | 1
07 Bielas de paralelogramo | 1 juego
08 Ejes, cojinetes y separadores | 1 lote
09 Resorte de compensación | 1
10 Portacabezal nivelado | 1
11 Horquilla de torreta | 1
12 Tambor y eje horizontal | 1 conj.
13 Servo selector | 1
14 Indexador, bloqueo y sensor | 1 conj.
15 Cartucho de lápiz con resorte | 1
16 Cartucho de electroimán | 1
17 Cartucho de pinza y microservo | 1
18 Sensores capacitivo + inductivo | 1 par
19 Arduino, potencia y fuente | 1 conj.
20 Tornillos, insertos y cableado | 1 lote
Allocate sufficient height to table, shrinking the operational drawing only if necessary.
3. Footer date 24-09-2026, add concise footer "70 g: objetivo por validar. Electroimán para ferromagnéticos." Keep "PROPUESTA CONCEPTUAL · SIN ESCALA · BOM PRELIMINAR".
4. Correct main arm balloons: 05 points upper arm from shoulder to elbow, 06 points forearm from elbow to wrist, 07 points slender linkage. The base servo is J1, shoulder J2, elbow drive J3.
Keep all typography in Spanish, no invented specs, no accuracy claims.

## Ajuste final del BOM de la segunda lámina

Edit ONLY the bottom BOM table strip in this image, preserving absolutely every other image region, drawing, labels, title, footer and style pixel for pixel. The table contains duplicated/missing numbers and incorrect labels. Replace that strip with four equal width tables next to each other, five data rows per table, each having three columns "N°", "Pieza", "Cant.". No illustrations in the strip. Draw ample room and type crisp small dark text. Do not attempt 10 rows in the short strip. Four blocks of exactly five rows as follows:
BLOCK ONE, IDs 01-05:
01 | Tablero y base fija | 1 conj.
02 | Plataforma J1 | 1
03 | Servos con encoder | 3
04 | Soportes de hombro | 1 par
05 | Brazo superior | 1
BLOCK TWO, IDs 06-10:
06 | Antebrazo | 1
07 | Bielas | 1 juego
08 | Ejes y cojinetes | 1 lote
09 | Resorte | 1
10 | Portacabezal | 1
BLOCK THREE, IDs 11-15:
11 | Horquilla | 1
12 | Tambor y eje | 1 conj.
13 | Servo selector | 1
14 | Bloqueo y sensor | 1 conj.
15 | Cartucho de lápiz | 1
BLOCK FOUR, IDs 16-20:
16 | Electroimán | 1
17 | Pinza y microservo | 1
18 | Sensores de material | 1 par
19 | Control y fuente | 1 conj.
20 | Tornillos y cableado | 1 lote
Each number 01 through 20 appears exactly once in this table. Do not merge rows. Do not repeat groups. Keep heading "LISTA DE MATERIALES (BOM PRELIMINAR)". Preserve date and conceptual footer.

Herramienta: image_gen integrada, dos generaciones independientes.

## Propuesta 01

Use case: infographic-diagram. Create a polished engineering proposal sheet for a university MathBot, in SPANISH. Wide landscape 3:2, very high resolution, ideally 3840 pixels wide. White warm drafting paper, graphite pencil outlines and crosshatching, faint construction lines, restrained pale blue mechanical panels, orange-red thin leaders and numbered balloons. Not a photorealistic render. Legible carefully typeset technical Spanish labels, clean generous whitespace, no labels crossing objects. A cohesive professional pencil technical drawing like an exploded assembly drawing, with full robot clearly visible. Main assembled perspective 55% left; exploded mechanism detail upper right; numbered illustrated parts layout and compact BOM lower strip/right. All parts numbered consistently. Include a drawing title block and clearly write "PROPUESTA CONCEPTUAL · SIN ESCALA · BOM PRELIMINAR". Do not claim manufacturing-ready dimensions, guaranteed accuracy, proven payload, or source model compatibility. Show the actual MathBot three-petal rose drawn in blue on paper on the table (one petal toward left, two toward upper/lower right), a metal test object labelled "70 g · objetivo de carga", and a separate nonmetal test object. End effector includes capacitive plus auxiliary inductive material sensing, electromagnet, a pen/pencil module, and mechanical gripper. Detection of material is distinct from tool-position sensing. A ballpoint/Sharpie held vertically, with spring compliant holder, traces the rose. The magnet is a wound coil on iron core, clearly NOT a suction cup. The mechanical gripper is two jaws, with small dedicated servo. Sensors point toward the target, not toward another metal tool. Tool exchange or selection happens lifted above the sheet. All cables have plausible routing. Keep the board beautiful, detailed and physically intelligible.
TITLE exactly: "MATHBOT / 01 — SCARA CON CAMBIO AUTOMÁTICO".
Input image 1 is a mechanical architecture and annotation reference only: HowToMechatronics blue SCARA with tall rod tower and two horizontal belt-driven arms. Create a NEW drawing adapting it, not copying its gripper. Retain recognisable base, 4 vertical guide rods, lead screw, sliding carriage, two horizontal articulated links, bearing-supported rotary joints and GT2 belts with tensioners; adapt to two planar joints plus Z, omit original rotary wrist. Main illustration has one pen module attached; rack holds the magnet and gripper modules plus one empty pen bay. TWO horizontal arm links each nominal 200 mm center-to-center, dimension arrows marked "200 mm · propuesta". Show small plan inset with "Centro de rosa: D = 220 mm" from base axis, not the outer board dimension. Four smooth rods and one central T8 lead screw raise both arm links on their carriage. Actuation proposal uses 2 encoder feedback rotary servos with toothed belts (not stock NEMA xy), plus one NEMA17 for Z, to adapt source geometry to course servomotor verification. Label "2R + Z". Do not label any reduction ratio.
Automatic changer enlarged exploded detail: wrist receiver flange, servo-operated radial sliding latch pin, mechanical tapered locating surfaces + antirotation key, contact pogo block, common tool adapter plate underneath. Dashed vertical axis shows assembly. Servo retracts pin only over a three-bay docking station; no magnetic-only coupling. Fixed sensor bracket alongside receiver remains on robot across tools. Rack bay descriptions "LÁPIZ", "ELECTROIMÁN", "PINZA". Each tool detachable; common plate seats into latch. Magnet wiring through pogo contacts from MOSFET driver with flyback diode. Separate micro switch confirms lock engagement.
BOM numbered exactly with small corresponding sketches and quantities, space it into two columns if needed:
01 Tablero de trabajo — 1
02 Base y giro J1 — 1 conj.
03 Servos con encoder — 2
04 Guías verticales — 4
05 Husillo T8 y tuerca — 1 conj.
06 Motor Z y acople — 1 conj.
07 Carro y cojinetes lineales — 1 conj.
08 Brazo 1 — 1
09 Junta J2 y rodamientos — 1 conj.
10 Brazo 2 — 1
11 Correas GT2, poleas y tensores — 2 juegos
12 Receptor y pestillo con servo — 1 conj.
13 Contactos y placas de herramienta — 1 juego
14 Sensores capacitivo + inductivo — 1 par
15 Portaplumas con resorte — 1
16 Electroimán bobinado — 1
17 Pinza y microservo — 1 conj.
18 Estación de tres puestos — 1
19 Arduino, potencia y fuente — 1 conj.
20 Tornillos, insertos y cableado — 1 lote
Use compact callouts on main assembled drawing for key numbers 02 03 04 05 06 07 08 09 10 12 14 15 18 19. Exploded detail identifies 12 13 14, and latch switch with descriptive label. Lower row shows 15 pen,16 magnet,17 gripper as separate complete cartridge modules. Brief sequence "ELEVAR → ESTACIONAR → LIBERAR → ACOPLAR → VERIFICAR". Tiny footer "Inspirado en HowToMechatronics; adaptación MathBot."

## Propuesta 02

Use case: infographic-diagram. Create a polished engineering proposal sheet for a university MathBot, in SPANISH. Wide landscape 3:2, very high resolution, ideally 3840 pixels wide. White warm drafting paper, graphite pencil outlines and crosshatching, faint construction lines, restrained pale blue mechanical panels, orange-red thin leaders and numbered balloons. Not a photorealistic render. Legible carefully typeset technical Spanish labels, clean generous whitespace, no labels crossing objects. A cohesive professional pencil technical drawing like an exploded assembly drawing, with full robot clearly visible. Main assembled perspective 55% left; exploded mechanism detail upper right; numbered illustrated parts layout and compact BOM lower strip/right. All parts numbered consistently. Include a drawing title block and clearly write "PROPUESTA CONCEPTUAL · SIN ESCALA · BOM PRELIMINAR". Do not claim manufacturing-ready dimensions, guaranteed accuracy, proven payload, or source model compatibility. Show the actual MathBot three-petal rose drawn in blue on paper on the table (one petal toward left, two toward upper/lower right), a metal test object labelled "70 g · objetivo de carga", and a separate nonmetal test object. End effector includes capacitive plus auxiliary inductive material sensing, electromagnet, a pen/pencil module, and mechanical gripper. Detection of material is distinct from tool-position sensing. A ballpoint/Sharpie held vertically, with spring compliant holder, traces the rose. The magnet is a wound coil on iron core, clearly NOT a suction cup. The mechanical gripper is two jaws, with small dedicated servo. Sensors point toward the target, not toward another metal tool. Tool exchange or selection happens lifted above the sheet. All cables have plausible routing. Keep the board beautiful, detailed and physically intelligible.
TITLE exactly: "MATHBOT / 02 — EEZY CON TORRETA MODULAR".
Input image 1 is the actual local MathBot Mk2 kinematic simulation (geometry reference only, not visual style). Render a mechanically plausible anthropomorphic EEZYbotARM Mk2 derivative with round rotating base, twin cheek shoulder supports, short rising upper arm, long descending forearm, paired parallelogram link rods maintaining distal carrier level. Clearly different from SCARA: articulated joints bend in vertical plane, no tall Z tower and no horizontal SCARA links. Three main encoder servos act on base/shoulder/elbow; shoulder counterbalance spring and bearings on both sides of joint. Proposed reinforced ribbed printed plates. Small side dimension inset shows reference chain only "L1 92 · L2 135 · L3 147 · L4 87 mm" with caption "Geometría del modelo; TCP nuevo por recalibrar". Mark "3 GDL + selector".
New automatic head is compact lightweight three-position drum turret on a HORIZONTAL axle, mounted in a U-yoke on level wrist carrier. Exactly THREE radial replaceable cartridges spaced 120 degrees: spring pen holder, wound-core electromagnet, 2-jaw gripper. In drawing the active pen points straight down; other two tools point obliquely up away from paper, avoiding collision. Servo/index drive mounted on stationary yoke rotates horizontal shaft; detent locking pin locks in each of 3 positions, microswitch confirms locked index, small separate home/index flag. Mechanical bearings support drum, servo shaft does not carry radial load alone. Tools held in screwed cartridges for maintenance, automatic selection occurs by rotating drum not removing tools. A fixed small side sensor bracket with capacitive plate and inductive probe points down toward test target; it does not rotate with drum. Cable service loop labelled "Giro limitado; retorno de cable"; do NOT suggest unlimited continuous spinning. Label "Seleccionar a altura segura".
Exploded turret upper right: yoke, shaft, pair of bearings, triangular 3-station drum, index disc, servo drive, locking pin + switch, three independent cartridges, cable connector; dotted aligned assembly axes. Show exactly one operational pen plus parked magnet and gripper on the assembled turret, and exploded duplicates confined to inset.
BOM numbered exactly:
01 Tablero y base fija — 1 conj.
02 Plataforma giratoria J1 — 1
03 Servos con encoder — 3
04 Soportes de hombro — 1 par
05 Brazo superior — 1
06 Antebrazo — 1
07 Bielas de paralelogramo — 1 juego
08 Ejes, cojinetes y separadores — 1 lote
09 Resorte de compensación — 1
10 Portacabezal nivelado — 1
11 Horquilla de torreta — 1
12 Tambor y eje horizontal — 1 conj.
13 Servo selector — 1
14 Indexador, bloqueo y sensor — 1 conj.
15 Cartucho de lápiz con resorte — 1
16 Cartucho de electroimán — 1
17 Cartucho de pinza y microservo — 1
18 Sensores capacitivo + inductivo — 1 par
19 Arduino, potencia y fuente — 1 conj.
20 Tornillos, insertos y cableado — 1 lote
Main numbered leader labels identify 02 03 04 05 06 07 09 10 11 15 18 19. Highlight automatic head zoom with 11 through 18. Pen coil and spring are distinct from magnet coil.
Brief sequence "ELEVAR → DESBLOQUEAR → GIRAR 120° → BLOQUEAR → VERIFICAR".
Footer "Derivado de EEZYbotARM Mk2 / easyEEZYbotARM. Validar carga, colisiones y límites reales."

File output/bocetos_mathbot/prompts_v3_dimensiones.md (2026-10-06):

# Rediseño funcional con cotas

## Corrección del cabezal EEZY

Correct ONLY the distal L4 support and head arrangement of this engineering sheet, keeping the title, full arm, all other dimensions and angle values, drawing style and footer.
The current "L4 = 87 mm (ref.)" horizontal extension is an EMPTY rod protruding right while tools hang at its start; this is wrong. Replace it with a SHORTER-IN-PERSPECTIVE but still labelled 87 mm horizontal level carrier that starts at the wrist pivot and ENDS at the head mounting plate. Move and attach the ENTIRE simple combined head (fixed downward electromagnet, capacitive+inductive sensor pair, hinged clamp and downward pen) rigidly to the distal END of that carrier. The dimension line L4 must span from wrist reference axis to head/pen mount reference axis, NOT to an unused stick. There must be NO unused horizontal rod beyond the head. Move the pen contact point and rose paper slightly right if necessary while keeping everything within generous portrait page margins. Compact the head footprint to prevent clipping. The pen clamp must look like a SMALL split collar or two clamping jaws gripping the PEN with a screw. The single auxiliary servo beside collar hinges the holder about a horizontal shaft. Keep downward fixed electromagnet SIDE BY SIDE with pen and sensor bracket. Only pen tip touches paper. No pen through magnet. The ghost outline for stowed pen must pivot around the SAME clamp hinge and show pen rotated 90 degrees; do not depict an unrelated floating pen. Preserve labels "Electroimán fijo", "Sensores: capacitivo + inductivo", "Servo de abatimiento", "Pinza portaplumas" and "0° / 90°", place leaders correctly. All four arm dimensions and the numerical joint angle block remain unchanged. Add tiny "Sin escala" footer. Do not change dimensions, invent new motors, reintroduce turret or add extra diagrams.

## Corrección final: L4 como parámetro original

Make one precise correction to this image. DELETE the horizontal light-blue bar that projects right from the wrist above the sensors, including its cable loop on top and the "L4 = 87 mm (ref.)" double-ended orange dimension line. Leave the existing combined electromagnet/sensor/pen assembly in its current position attached by its small mounting plate directly beneath the wrist. Do not add a replacement projecting bar. In the white space freed above the head write this compact two-line note in dark type with NO dimension arrows: "L4 del modelo original: 87 mm" and "Offset de herramienta por recalibrar". This is a model parameter, not a dimension of the new bracket. Everything else stays exactly the same: L1=92, L2=135, L3=147 dimension lines, joint angles, text, robot, head, curve, portrait style. Also remove the dashed horizontal ghost PEN near the active pencil because its drawn hinge position is misleading; retain the small "0° / 90°" curved arrow by the auxiliary servo as the motion indication. Do not add any other content.

ImageGen integrada. El ejemplo del usuario se usa como inspiración funcional, no como plano validado.

## SCARA

Use case: infographic-diagram. EDIT the supplied previous MathBot portrait drawing into a revised, SIMPLER functional concept with dimension arrows and joint motion annotations. Portrait 2:3, high resolution, pure white background, one full assembled robot only, thin graphite engineering pencil outlines, very pale blue panels, restrained orange leader arrows, blue curve on paper. Generous print margins, short readable Spanish labels. No BOM, no exploded views, no secondary robot, no separate diagrams or giant text blocks. Keep reference drawing's identifiable architecture and drawing style.

CRITICAL COMMON HEAD REDESIGN: REMOVE ALL previous turret, carousel, tool changing couplers, indexing drum, automatic tool racks, spare grippers and tool storage. Instead one SMALL SIMPLE FIXED L-SHAPED PLATE on wrist holds a fixed downward electromagnet (short iron-core copper wound cylinder, flat exposed bottom pole), a fixed compact material sensor bracket to one SIDE clear of magnet with capacitive presence sensor and inductive metal detector, and on OTHER SIDE a pen-holding clamp. The clamp is two small jaws/halves tightened by a screw to hold the PEN ONLY, NOT a large pick-and-place claw. One small auxiliary servo hinges this clamp+pen assembly from vertical writing to horizontal parked (90 degrees). Show pen vertical touching paper, magnet several mm ABOVE paper so it doesn't drag; use a thin dashed ghost-outline of ONLY pen in horizontal parked state with one curved arrow "0° / 90°". Pen and magnet are distinct SIDE-BY-SIDE tools; DO NOT put pen through or below the magnet on its centerline. Sensor sensing faces point toward the target area, not toward the coil or pen. No sensor sharing a gripper finger. Label exactly "Pinza portaplumas", "Servo de abatimiento", "Electroimán fijo", and "Sensores: capacitivo + inductivo". Keep head compact and simple, plausible hardware at the physical tip. The electromagnet and sensors stay assembled together throughout work. Pen must fold out of way before pickup.

Bottom small two-line caption, NOT boxed flowchart: 
"Detectar con imán OFF → clasificar → alinear → activar"
"No metálico: OFF · Metal ferromagnético: recoger"
Tiny footnote "Ángulos de referencia; recalibrar con el cabezal final."
One small line near title "3 GDL del brazo + 1 auxiliar del lápiz".
Draw just ONE paper with the blue three-petal mathematical rose. No material test objects. Explicitly no claims of proven dimensions, performance, force or accuracy.
TITLE "MATHBOT · SCARA SIMPLIFICADO".
Preserve SCARA tower, sliding carriage, two horizontal links, belt-driven rotary joints. Make tower shorter in visual proportions to a compact tabletop robot; Z stroke is 60 mm, NOT tower length. NO tool rack anywhere. Label "Guías y husillo Z", "Base y control", "Correas y poleas". Shoulder rotates about vertical axis and elbow also rotates about vertical axis; add small curved arrows q1 at base/shoulder and q2 at elbow. Double-ended vertical arrow beside carriage reads "Z: carrera propuesta 60 mm".
Critical dimension lines center-to-center not outer casing: first link J1-J2 "L1 = 200 mm", second link J2-to-distal mount "L2 = 200 mm". These two arms appear approximately equal in physical length after perspective. Small note "Cotas propuestas entre ejes".
Compact text in free white space above arm, use exactly these four lines:
"Rangos para trazar la rosa"
"q1: −79,5° a −18,0°"
"q2: 83,4° a 146,0°"
"Centro: (220, 0) mm"
These are REQUIRED trajectory angles, not servo travel limits. Add text "3 GDL: q1, q2, Z" near shoulder. Paper rose has one petal pointing in -X, two in +X quadrants. Tiny XY arrows on work surface identify +X direction from base toward rose center, +Y lateral. Never put 360 degrees on any joint. Drawing order emphasizes robot and simple combined head, only short annotated dimensions and above reference angle block. Add small "Sin escala · Propuesta" footer.

## EEZY

Use case: infographic-diagram. EDIT the supplied previous MathBot portrait drawing into a revised, SIMPLER functional concept with dimension arrows and joint motion annotations. Portrait 2:3, high resolution, pure white background, one full assembled robot only, thin graphite engineering pencil outlines, very pale blue panels, restrained orange leader arrows, blue curve on paper. Generous print margins, short readable Spanish labels. No BOM, no exploded views, no secondary robot, no separate diagrams or giant text blocks. Keep reference drawing's identifiable architecture and drawing style.

CRITICAL COMMON HEAD REDESIGN: REMOVE ALL previous turret, carousel, tool changing couplers, indexing drum, automatic tool racks, spare grippers and tool storage. Instead one SMALL SIMPLE FIXED L-SHAPED PLATE on wrist holds a fixed downward electromagnet (short iron-core copper wound cylinder, flat exposed bottom pole), a fixed compact material sensor bracket to one SIDE clear of magnet with capacitive presence sensor and inductive metal detector, and on OTHER SIDE a pen-holding clamp. The clamp is two small jaws/halves tightened by a screw to hold the PEN ONLY, NOT a large pick-and-place claw. One small auxiliary servo hinges this clamp+pen assembly from vertical writing to horizontal parked (90 degrees). Show pen vertical touching paper, magnet several mm ABOVE paper so it doesn't drag; use a thin dashed ghost-outline of ONLY pen in horizontal parked state with one curved arrow "0° / 90°". Pen and magnet are distinct SIDE-BY-SIDE tools; DO NOT put pen through or below the magnet on its centerline. Sensor sensing faces point toward the target area, not toward the coil or pen. No sensor sharing a gripper finger. Label exactly "Pinza portaplumas", "Servo de abatimiento", "Electroimán fijo", and "Sensores: capacitivo + inductivo". Keep head compact and simple, plausible hardware at the physical tip. The electromagnet and sensors stay assembled together throughout work. Pen must fold out of way before pickup.

Bottom small two-line caption, NOT boxed flowchart: 
"Detectar con imán OFF → clasificar → alinear → activar"
"No metálico: OFF · Metal ferromagnético: recoger"
Tiny footnote "Ángulos de referencia; recalibrar con el cabezal final."
One small line near title "3 GDL del brazo + 1 auxiliar del lápiz".
Draw just ONE paper with the blue three-petal mathematical rose. No material test objects. Explicitly no claims of proven dimensions, performance, force or accuracy.
TITLE "MATHBOT · BRAZO SIMPLIFICADO".
Preserve EEZY robot as a COMPACT anthropomorphic parallelogram arm, not a giant industrial robot. Three main joints: q1 base yaw vertical axis, q2 shoulder pitch at height 92 mm, q3 elbow relative bend. Shoulder at 92 mm must be lower than upper link length 135 mm; do NOT draw the very tall shoulder structure from reference image. Upper link 135 mm rises from shoulder to elbow, forearm 147 mm descends toward wrist. Pair of parallel rods and level end carrier. Keep base/shoulder motors low, transmission bielas, small counterbalance spring optional but do not exaggerate it. Fixed distal forward extension originally 87 mm, label it reference offset and do not confuse with downward pen length. NO turret. Use common simple head described above.
Dimension arrows accurately placed:
"L1 = 92 mm" vertical from base datum to shoulder pivot;
"L2 = 135 mm" center-to-center shoulder-elbow;
"L3 = 147 mm" center-to-center elbow-wrist;
"L4 = 87 mm (ref.)" on horizontal wrist-to-original-tool offset extension.
Add short labels "Bielas de paralelogramo" and "Base giratoria q1".
Small curved arrows q2 at shoulder, q3 at elbow. q3 is relative elbow bend NOT absolute forearm angle.
In available white area show exactly:
"Rangos del modelo para la rosa"
"q1: −22,7° a 22,7°"
"q2: 6,6° a 26,4°"
"q3: −136,2° a −50,8°"
Small sentence below "Referencia: centro (250, 0) mm; z = 5 mm".
Further concise orange annotation "Adaptar hombro: el límite original inicia en 39°".
The reference angles apply to the ORIGINAL mathematical tool point, not to the new physical pen tip; label beside L4 "Nuevo punto de herramienta por calibrar". Do not claim validated tabletop reach with the original hardware. Geometry is nominal source chain and proposed head. Preserve balanced print layout and prominent robot.

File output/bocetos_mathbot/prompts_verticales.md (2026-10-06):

# Láminas verticales simplificadas

Herramienta: ImageGen integrada. Una imagen independiente por diseño.

## SCARA

Use case: infographic-diagram. Simplify and recompose the supplied MathBot technical illustration into ONE clean PORTRAIT page for printing on a blank white sheet. Output vertical 2:3 aspect ratio, high resolution. Only ONE assembled isometric robot scene, with short Spanish part-name labels and thin orange-red leader arrows. Large robot occupies most of page, all parts fully visible, clear pen-and-pencil engineering sketch outlines with very light pale-blue panels and graphite hatching. Pure WHITE background, no paper texture, no gray background, very sparse shading to save printer ink. Maintain at least 6% safe white margins on every edge. Small understated title at top. No BOM tables, no exploded views, no plan views, no closeups, no process steps, no feature checklists, no numbers in circles, no dimension lines, no drawing border, no title block, no logos. Labels must be readable at letter/A4 size and arranged with space around the robot without overlapping it or each other. Ground the robot on a simple thin rectangular tabletop platform in the lower third with a paper showing the MathBot three-petal rose curve in blue. Keep only the robot assembly and essential working accessories. Do not crop any label or robot part. This is simplified PRESENTATION, preserve mechanical architecture rather than inventing a different robot. Small footer only "Boceto conceptual · Sin escala".
Title: "MATHBOT · SCARA".
Image 1 is the user's crop showing exactly the intended content level: keep the assembled blue SCARA and its nearby three-position tool rack. Remove the small plan-view inset from the reference completely. Recompose in a vertical page, with tall four-guide-rod tower rising in upper left/center and two horizontal belt-driven arm links folding towards the right and foreground to fit portrait. Keep motor on top driving vertical lead screw, sliding arm carriage, rotary base, 2 arm links, visible belts, pen pointing downward at the end, fixed compact material sensors adjacent to head. Automatic modular receiver at wrist. Pen attached to robot; nearby small tool rack holds one wound-iron-core electromagnet and one servo mechanical gripper, with the pen bay EMPTY. Draw only three tool bays, labels "Lápiz", "Electroimán", "Pinza". The pencil is a writing marker held with small compliant spring.
Place these short callouts with neat leaders pointing accurately:
"Motor Z" to top motor
"Husillo" to central threaded screw
"Guías verticales" to smooth rods
"Carro deslizante" to carriage
"Brazo 1" to proximal horizontal link
"Brazo 2" to distal horizontal link
"Correas y poleas" to exposed belt
"Base y control" to robot base/electronics housing
"Acople automático" to wrist receiver
"Sensores de material" to fixed sensor pair
"Lápiz / Sharpie" to vertical writing tool
"Estación de herramientas" to rack.
A small label "Rosa de tres pétalos" near the paper. No other text. No test cubes or metal test weights. Main assembled view only.

## Brazo articulado

Use case: infographic-diagram. Simplify and recompose the supplied MathBot technical illustration into ONE clean PORTRAIT page for printing on a blank white sheet. Output vertical 2:3 aspect ratio, high resolution. Only ONE assembled isometric robot scene, with short Spanish part-name labels and thin orange-red leader arrows. Large robot occupies most of page, all parts fully visible, clear pen-and-pencil engineering sketch outlines with very light pale-blue panels and graphite hatching. Pure WHITE background, no paper texture, no gray background, very sparse shading to save printer ink. Maintain at least 6% safe white margins on every edge. Small understated title at top. No BOM tables, no exploded views, no plan views, no closeups, no process steps, no feature checklists, no numbers in circles, no dimension lines, no drawing border, no title block, no logos. Labels must be readable at letter/A4 size and arranged with space around the robot without overlapping it or each other. Ground the robot on a simple thin rectangular tabletop platform in the lower third with a paper showing the MathBot three-petal rose curve in blue. Keep only the robot assembly and essential working accessories. Do not crop any label or robot part. This is simplified PRESENTATION, preserve mechanical architecture rather than inventing a different robot. Small footer only "Boceto conceptual · Sin escala".
Title: "MATHBOT · BRAZO ARTICULADO".
Image 1 is the previous EEZY sheet. Keep ONLY the main assembled EEZY robot from its LEFT half, with the three-tool radial turret attached. Delete all right-half diagrams and all bottom tables. Compose as a tall attractive central robot filling portrait page: circular rotating base low left, shoulder above base, upper arm rising, articulated forearm extending down-right to the head. Keep twin shoulder cheeks, paired parallel linkage rods, shoulder spring, and the three servo architecture. Light pale blue printed mechanical plates, visible bolts, restrained wiring.
Preserve the functional radial 3-position turret: horizontal axle, pen cartridge aimed down as active tool, iron-core copper-coil electromagnet cartridge aimed obliquely UP-LEFT, mechanical gripper aimed obliquely UP-RIGHT, exactly 3 cartridges. Sensor pair on stationary bracket beside the downward pencil outside rotating envelope. No external tool rack for this robot. Marker tip touching paper at one point of a three-petal rose. No spare tools, no test cubes or weights. No separate drawings.
Place these short callouts with neat leaders:
"Base giratoria" to base
"Servomotores" to actuators
"Hombro" to shoulder pivot
"Brazo superior" to upper arm
"Antebrazo" to forearm
"Bielas" to slender parallel link rods
"Resorte" to shoulder counterbalance spring
"Cabezal modular" to turret assembly
"Electroimán" to copper wound coil on iron core
"Pinza" to mechanical jaw cartridge
"Sensores de material" to fixed sensor pair
"Lápiz / Sharpie" to active downward writing marker.
Small label "Rosa de tres pétalos" by the paper. No other text.

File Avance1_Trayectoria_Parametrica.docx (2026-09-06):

PBL MATHBOT · Cálculo III · Entregable 1 · 7 % de la nota final

Determinación y validación inicial

de la trayectoria paramétrica

Matemática Multivariable y Ecuaciones Diferenciales · Key Institute

## Equipo

Nombre del equipo | SCARABOT
Integrante 1 | José Santiago Merino Herrera
Integrante 2 | Guillermo Andrés Córdova Quiñonez
Integrante 3 | Camila Margarita Julian Vargas
Integrante 4 | Andrea Maria Lopez Meardi
Fecha de entrega | 04/09/2026

## Resumen

La referencia asignada es una trayectoria plana de tres lóbulos que se cruzan en el origen. El equipo propone una única ecuación paramétrica continua, sin definición por tramos, construida como una rosa polar de tres pétalos compuesta con una transformación afín que estira el plano sobre el eje Y. El modelo se estimó por dos caminos independientes y se validó contra 600 puntos digitalizados del trazo físico. Bajo la métrica declarada en la sección 10, la desviación máxima es del 4.96 % del radio máximo y la desviación cuadrática media del 1.96 %.

Nota de revisión posterior al Avance 1: la ecuación de la sección 4 se verificó contra una segunda referencia independiente —la imagen de la curva asignada en el enunciado, medida píxel a píxel— y la reproduce con una desviación máxima del 1.42 % del radio, dentro del ancho del propio trazo del dibujo. En el proceso se detectó que el dataset digitalizado con WebPlotDigitizer tenía el eje Y comprimido cerca de un 20 %, lo que en una revisión anterior llevó a un valor de k equivocado. La sección 14 documenta la medición, la corrección del dataset y la justificación de por qué la curva es la misma rosa polar de tres pétalos compuesta con un estiramiento afín.

# 1. Trayectoria de referencia

La referencia proporcionada es una trayectoria plana cerrada con tres lóbulos que se intersectan en un punto común. La figura siguiente reproduce el trazo tal como fue entregado al equipo.

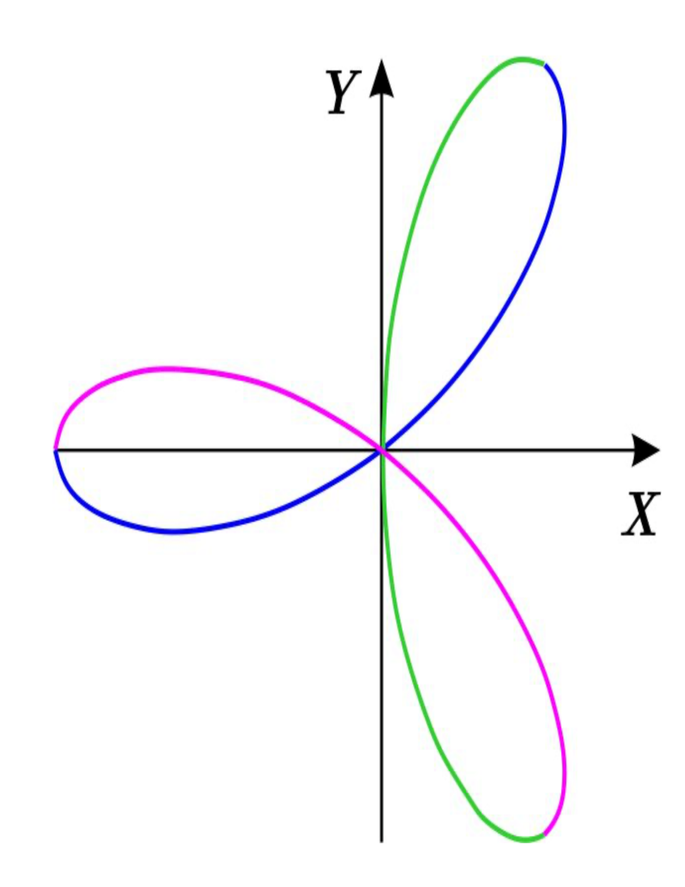
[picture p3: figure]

Figura 1. Trayectoria de referencia proporcionada

## 1.1 Captura de la referencia

La referencia se capturó por dos vías complementarias. La primera es la medición directa con regla sobre el trazo físico, aplicada a las tres puntas de lóbulo. La segunda es la digitalización completa del contorno, que produjo 600 puntos ordenados en coordenadas cartesianas, con el origen en el punto de cruce de los tres lóbulos y el eje X alineado con el lóbulo menor.

La digitalización recorre la curva en tres tramos de 200 puntos, con un paso medio de 1.21 mm entre puntos consecutivos. El ruido punto a punto, estimado por la segunda diferencia de las coordenadas, tiene una mediana de 0.024 mm, dos órdenes de magnitud por debajo de la resolución de la regla. El orden de recorrido de la captura es lóbulo sobre el eje X negativo, lóbulo del primer cuadrante, lóbulo del cuarto cuadrante.

## 1.2 Datos de partida

Magnitud | Regla | Digitalización | Razón
Punta del lóbulo menor (eje X negativo) | 10.0 cm | 8.850 cm | 1.130
Punta de los lóbulos mayores (Q1 y Q4) | 13.0 cm | 11.150 cm | 1.166
Razón entre lóbulo mayor y menor | 1.300 | 1.2599 | —

La última fila es la que gobierna la forma: las dos capturas coinciden en la proporción entre lóbulos dentro de un 3 %. Las dos primeras difieren por un factor común cercano a 1.155, lo que indica un error de escala en la digitalización y no una discrepancia de forma. El tratamiento aparece en la sección 11.1.

# 2. Análisis de las características geométricas

Antes de proponer ninguna ecuación se caracterizó la curva mediante descriptores que no dependen de un modelo previo. Estos descriptores son los que después restringen la familia de curvas admisible.

Característica | Observación sobre la referencia
Número de lóbulos | Tres, cerrados, sin extremos libres.
Punto de intersección | Único y común a los tres lóbulos. La curva lo visita tres veces, con tangentes distintas en cada paso.
Simetría | Especular respecto del eje X. Las puntas de los dos lóbulos mayores están a ±66.88° medidos desde el eje X positivo.
Tamaño de los lóbulos | Desigual. El lóbulo alineado con el eje X negativo mide 10 cm; los otros dos, 13 cm.
Sector angular ocupado | El lóbulo menor abarca 77.25° y los mayores 49.46° cada uno. Suman 176.2°, con separaciones entre lóbulos.
Cierre | La curva es cerrada: el punto inicial y el final de la digitalización coinciden en el origen.
Regularidad | No se observan esquinas ni retrocesos. La tangente varía de forma continua incluso al pasar por el origen.

Consecuencia para el modelado. Tres lóbulos con un punto de cruce triple y simetría especular apuntan a una rosa polar de frecuencia impar. La desigualdad entre lóbulos descarta la rosa simétrica pura y obliga a introducir un mecanismo adicional, que la sección 3 identifica como una transformación afín.

# 3. Proceso de estimación y modelado

Esta sección deja por escrito cómo se llegó a la familia de curvas elegida, no solo cuál fue el resultado.

## 3.1 Familias candidatas y criterio de descarte

Se evaluaron cuatro familias compatibles con una figura cerrada de tres lóbulos. El criterio de descarte fue geométrico, aplicado antes de cualquier ajuste numérico, y se apoya en los descriptores de la sección 2.

Familia candidata | Resultado
Lemniscata de Bernoulli | Descartada. Produce dos lóbulos y no admite un tercero por variación de parámetros.
Curva de Lissajous con razón 3:1 | Descartada. Genera lóbulos de tamaños desiguales pero sin un punto de intersección triple; los cruces ocurren fuera del origen.
Epitrocoide | Descartada. Los lóbulos no se cierran en el origen y la curvatura en su base no coincide con la referencia.
Rosa polar con n impar | Aceptada. Tres lóbulos, cruce triple en el origen, curva cerrada y una sola expresión continua.

## 3.2 Construcción de la parametrización

Se parte de la rosa en coordenadas polares, donde la figura se describe con una sola línea de álgebra:

r(θ) = −A · cos(3θ)

El exponente de la frecuencia angular se fija en n = 3 porque una rosa polar con n impar produce exactamente n pétalos, y la referencia tiene tres. El signo negativo no escala la curva, la rota: es lo que coloca uno de los tres lóbulos sobre el eje X negativo, que es la orientación observada.

La conversión a forma paramétrica es directa tomando el ángulo polar como parámetro:

x(t) = r(t) · cos t y(t) = r(t) · sin t

Esta rosa es simétrica: sus tres pétalos miden lo mismo, y la referencia no. Para introducir la desigualdad sin recurrir a una definición por tramos se compone la curva con la transformación lineal diag(1, k), que estira el plano sobre el eje Y sin tocar el eje X:

(x, y) ↦ (x, k · y)

La composición de una curva continua con una transformación afín sigue siendo una curva continua, de modo que el resultado se expresa con una sola pareja de funciones. Sustituyendo se obtienen las ecuaciones de la sección 4.

## 3.3 Estimación de los parámetros

Los parámetros se estimaron por dos caminos que no comparten información, lo que permite contrastarlos en lugar de aceptar un único ajuste.

1. Estimación geométrica. La amplitud A se lee directamente de la punta del lóbulo menor, cuya distancia al origen es igual a A por construcción, ya que en ese punto y = 0 y el factor k no interviene. El factor k se despeja de la razón entre las puntas medidas.
2. Ajuste por mínimos cuadrados. Se minimiza la suma de los cuadrados de las distancias perpendiculares de los 600 puntos digitalizados a la curva, con A y k libres. El ajuste devuelve k = 1.329.

Los dos caminos coinciden en el factor de anisotropía dentro de un 2 %. Ese es el resultado relevante, porque k determina la forma de la curva con independencia de la escala. El valor adoptado es k = 1.3552.

# 4. Ecuaciones paramétricas propuestas

x(t) = −A · cos( n(t − φ) ) · cos t

y(t) = −A · k · cos( n(t − φ) ) · sin t

t ∈ [ 5π/6 , 11π/6 ]

Es una sola expresión continua y derivable en todo el dominio, sin ramas ni condiciones.

## 4.1 Escala y parámetros del modelo

Parámetro | Valor | Unidad | Cómo se obtuvo
A · amplitud base | 10.29 | cm | punta del lóbulo menor, medida con regla y contrastada con el trazo digitalizado
k · factor de anisotropía | 1.3552 | adimensional | razón entre puntas de lóbulo y ajuste por mínimos cuadrados
n · frecuencia angular | 3 | adimensional | conteo directo de lóbulos
φ · fase | 0 | rad | alineación del eje X con el lóbulo menor
t · dominio | [5π/6, 11π/6] | rad | sección 5

El modelo trabaja en centímetros y a escala real: las coordenadas que devuelven x(t) e y(t) son directamente las del trazo físico, sin factor de conversión intermedio. El radio máximo de la curva es de 13.16 cm y la longitud de arco total sobre el dominio declarado es de 81.44 cm.

# 5. Dominio y orientación

## 5.1 Elección del dominio

Se adopta t ∈ [5π/6, 11π/6], un intervalo de longitud π. La elección responde a tres razones.

1. Longitud mínima. Con n impar, la curva completa se recorre en medio giro del parámetro. Un intervalo de longitud 2π volvería a trazar la misma figura encima, sin agregar geometría y duplicando el tiempo de ciclo del mecanismo.
2. Extremos en el origen. En t = 5π/6, 7π/6, 3π/2 y 11π/6 se cumple cos(3t) = 0, es decir r = 0. El recorrido arranca en el origen, vuelve al origen entre lóbulo y lóbulo y cierra en el origen. Esos cuatro instantes son los únicos donde tiene sentido bajar o levantar la herramienta.
3. Correspondencia con la referencia. El orden de recorrido que produce este intervalo es lóbulo del eje X negativo, lóbulo Q1, lóbulo Q4, que coincide con el orden en el que se digitalizó el trazo físico.

## 5.2 El intervalo recorre la curva una sola vez

La rosa satisface r(t + π) = −A·cos(3t + 3π) = A·cos(3t) = −r(t). El cambio de signo del radio equivale a reflejar el punto por el origen, y esa reflexión coincide con el avance de π en el ángulo polar. En consecuencia el segundo medio giro reproduce punto por punto el trazo del primero, y cualquier intervalo de longitud π recorre la curva completa exactamente una vez, sin repeticiones ni huecos.

## 5.3 Orientación y sentido de recorrido

La fase φ = 0 fija la orientación observada: un lóbulo centrado en el eje X negativo y los otros dos simétricos respecto de ese eje. El signo negativo de la amplitud es el responsable de que el lóbulo alineado con el eje X caiga sobre el semieje negativo y no sobre el positivo.

El sentido de recorrido queda determinado por el crecimiento de t. Partiendo del origen en t = 5π/6, la curva entra al lóbulo del eje X negativo, regresa al origen, recorre el lóbulo del primer cuadrante, vuelve al origen, recorre el del cuarto cuadrante y cierra. Las flechas de la Figura 2 marcan ese sentido sobre el trazo.

# 6. Relación entre las ecuaciones y la forma de la trayectoria

Cada elemento de la ecuación controla una característica identificable de la curva. La correspondencia es la siguiente.

Elemento de la ecuación | Qué produce en la trayectoria
cos(3t) | Genera los tres lóbulos. El factor 3 hace que el radio cambie de signo seis veces en un giro completo, y al ser impar los pétalos se superponen de a pares, dejando tres distintos.
Ceros de cos(3t) | Son los pasos por el origen. Producen el punto de intersección triple y separan un lóbulo del siguiente.
Signo negativo de A | Rota la figura media división de pétalo, colocando un lóbulo sobre el eje X negativo en vez del positivo.
Factor A | Escala la figura de forma uniforme. Fija el tamaño del lóbulo menor, que es exactamente A.
Factor k sobre y(t) | Estira el plano sobre el eje Y. Deja intacto el lóbulo del eje X, alarga los otros dos hasta 13.16 cm y desplaza sus puntas de 60° a 68.05°.
cos t y sin t | Convierten el radio polar en coordenadas cartesianas. Son los que hacen girar el punto alrededor del origen mientras el radio oscila.
Fase φ | Rota la figura completa. Con φ = 0 la orientación coincide con la referencia y no hace falta corregirla.

El contraste directo entre lo que predice el modelo y lo que se mide sobre la referencia confirma esa correspondencia:

Descriptor geométrico | Modelo | Referencia | Diferencia
Punta del lóbulo menor | 10.29 cm | 10 cm (regla) | 2.9 mm
Punta de los lóbulos mayores | 13.16 cm | 13 cm (regla) | 1.6 mm
Ángulo de las puntas mayores | 68.05° | 66.88° | 1.17°
Sector angular del lóbulo menor | 76.08° | 77.25° | 1.17°
Sector angular de los mayores | 51.96° | 49.46° | 2.50°

# 7. Justificación matemática

## 7.1 Regularidad de la curva

Derivando la ecuación paramétrica se obtiene:

x′(t) = A [ n·sin(n(t−φ))·cos t + cos(n(t−φ))·sin t ]

y′(t) = A·k [ n·sin(n(t−φ))·sin t − cos(n(t−φ))·cos t ]

El vector velocidad no se anula en ningún punto del dominio. En los cuatro instantes donde la curva toca el origen se tiene cos(3t) = 0 y por tanto sin(3t) = ±1, de modo que las derivadas se reducen a x′ = ±3A·cos t e y′ = ±3A·k·sin t, que no pueden anularse a la vez. La rapidez mínima sobre el dominio es de 10.84 cm/rad y la máxima de 41.84 cm/rad.

La consecuencia práctica es que la trayectoria no tiene cúspides: el efector nunca debe detenerse e invertir el sentido, ni siquiera al pasar por el origen. Esto coincide con lo observado en la referencia, donde la tangente varía de forma continua.

## 7.2 Punto de intersección triple

El origen es la única autointersección de la curva y se visita tres veces, con tangentes separadas 60° entre sí en la rosa simétrica, y algo menos tras el estiramiento. En todos los demás puntos la curva es simple. Este comportamiento es el que distingue a la rosa de las familias descartadas en la sección 3.1, y es también la característica más visible de la referencia.

## 7.3 Cierre de clase C¹

Evaluando en los extremos del dominio, la posición coincide, P(5π/6) = P(11π/6) = (0, 0), y el vector velocidad también. La trayectoria es cerrada y suave en la costura, lo que permite repetir el ciclo sin discontinuidad en la velocidad al reiniciar.

## 7.4 Forma cartesiana implícita

Eliminando el parámetro mediante la identidad cos(3θ) = 4cos³θ − 3cosθ y sustituyendo cos θ = x/r se llega a:

( x² + y²/k² )² = A · x · ( 3y²/k² − x² )

La expresión se verifica en dos puntos independientes. En t = 180° ambos miembros valen A⁴, y en t = 240° vuelven a valer A⁴. La forma implícita confirma que la curva es algebraica de grado cuatro y sirve como comprobación de la conversión de paramétrica a cartesiana.

## 7.5 Análisis diferencial

La rapidez de recorrido no es constante aunque t avance uniformemente: es máxima cerca de las puntas y mínima cerca del origen. La curvatura alcanza su valor máximo de 1.133 cm⁻¹ en las puntas, lo que corresponde a un radio de curvatura mínimo de 0.88 cm. Ese radio es la restricción geométrica que el mecanismo debe poder seguir.

# 8. Visualización en MATLAB

Las figuras siguientes se generan con el archivo mathbot_avance1.m. Todas usan ejes rotulados en centímetros, relación de aspecto uno a uno mediante axis equal, y la misma escala que la referencia física, de modo que las magnitudes se pueden comparar directamente sobre el papel.

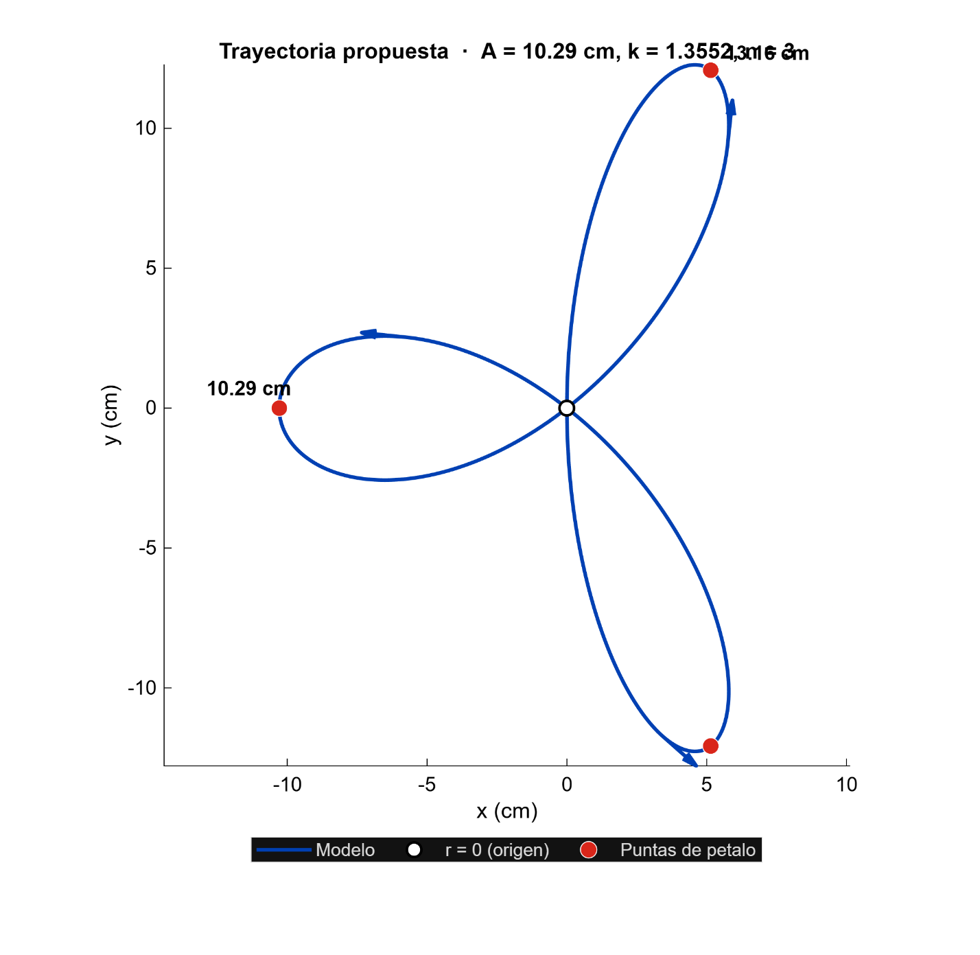
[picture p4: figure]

Figura 2. Trayectoria propuesta, dominio y sentido de recorrido

Se marcan los cuatro instantes con r = 0, que delimitan el dominio y separan los lóbulos, y las tres puntas. Las flechas indican el sentido de avance del parámetro.

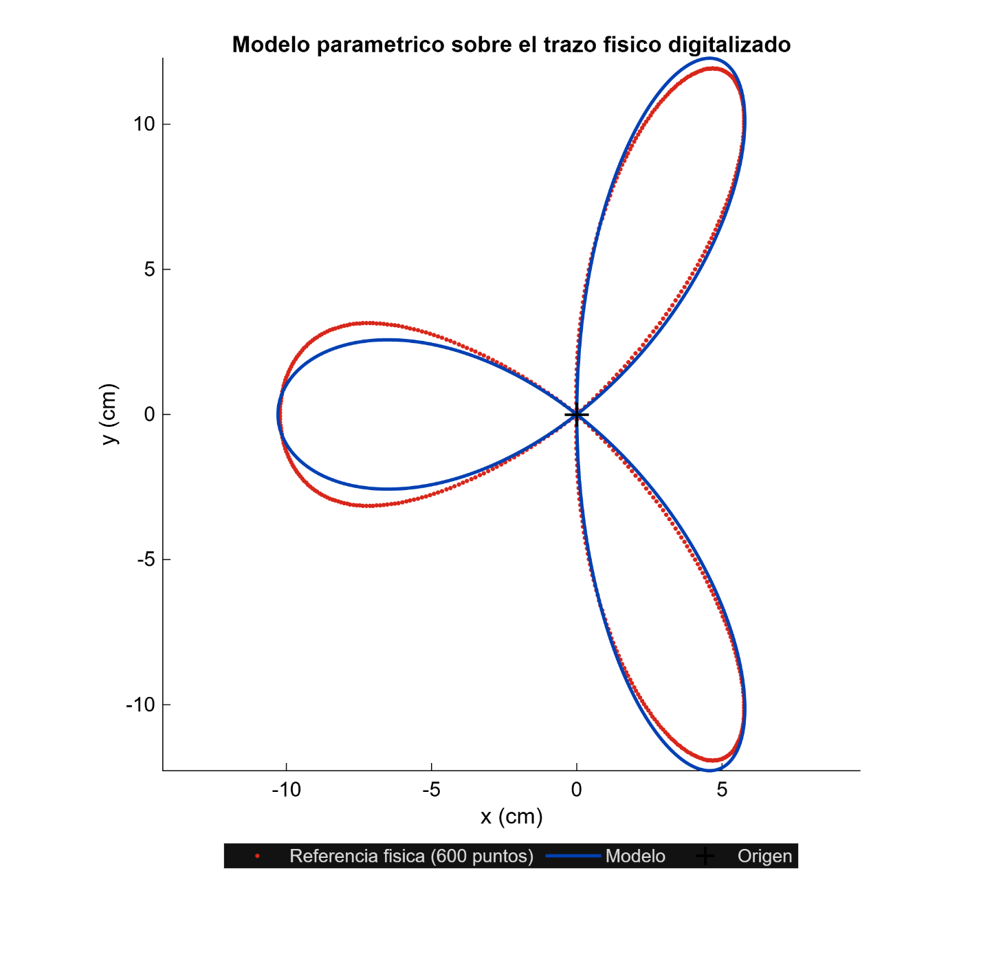
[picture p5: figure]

Figura 3. Modelo paramétrico sobre el trazo físico digitalizado

Superposición del modelo continuo sobre los 600 puntos de la referencia, tras la corrección de escala descrita en la sección 11.1. Es la comparación visual directa entre lo generado en MATLAB y la referencia proporcionada.

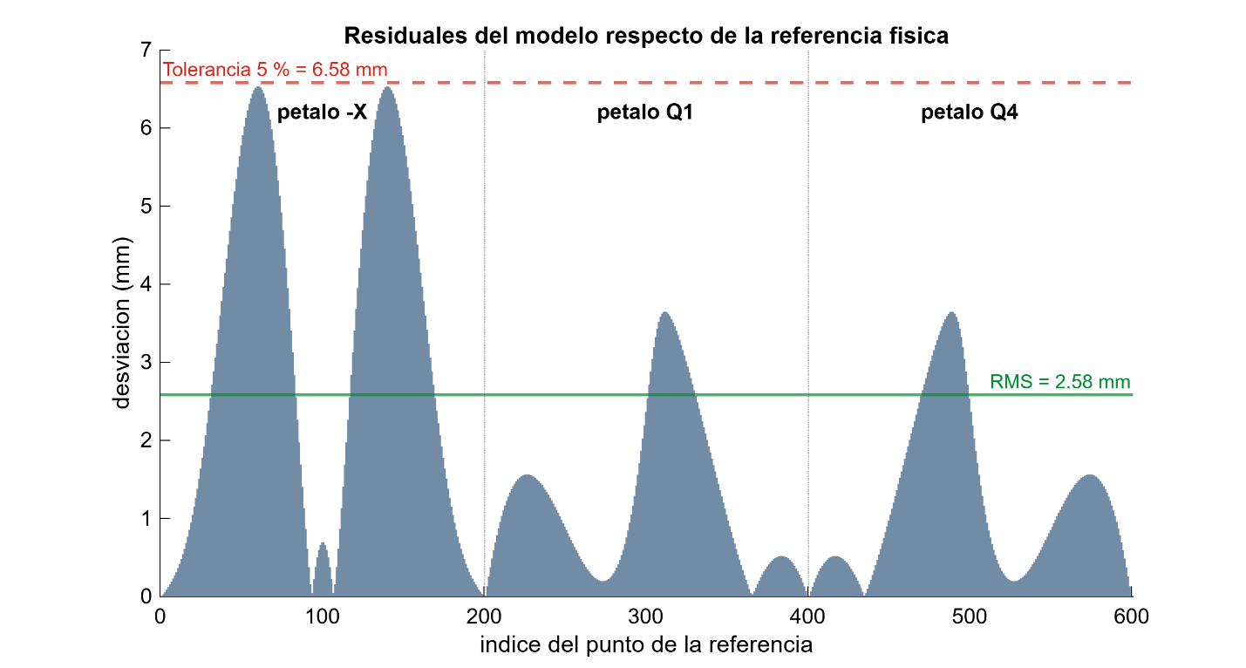
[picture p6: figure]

Figura 4. Residuales del modelo respecto de la referencia física

Desviación perpendicular de cada punto medido a la curva del modelo, con la banda de tolerancia y el valor cuadrático medio señalados. Las líneas verticales separan los tres lóbulos.

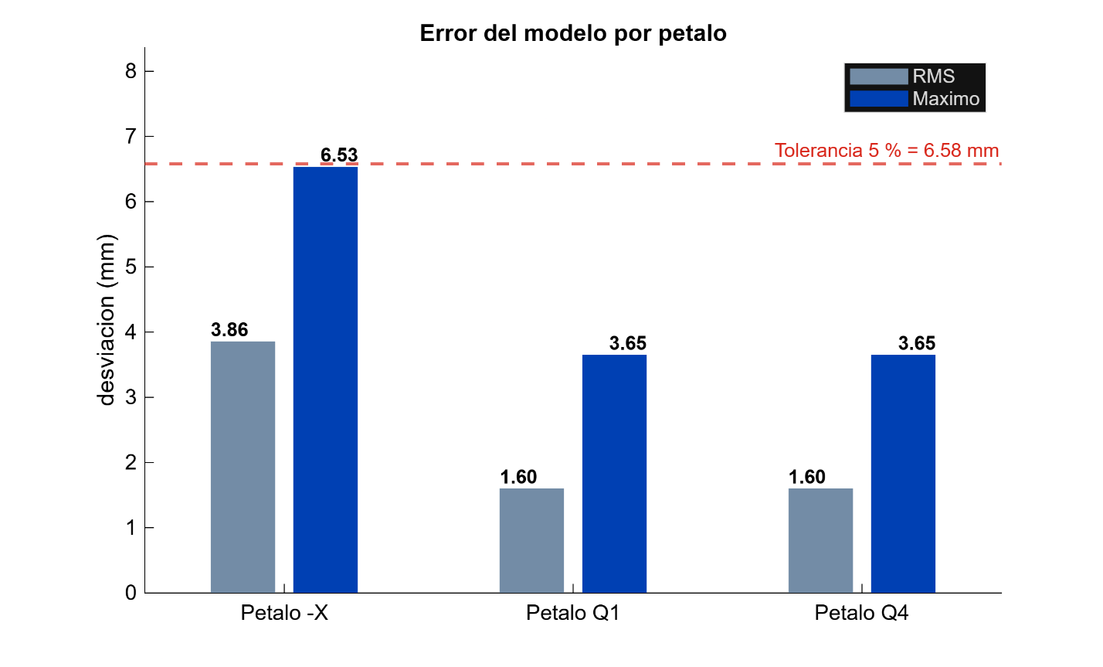
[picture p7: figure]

Figura 5. Error del modelo por lóbulo

Valor cuadrático medio y máximo del residual en cada tramo. Muestra que el error no está repartido de forma homogénea, lo que se analiza en la sección 11.2.

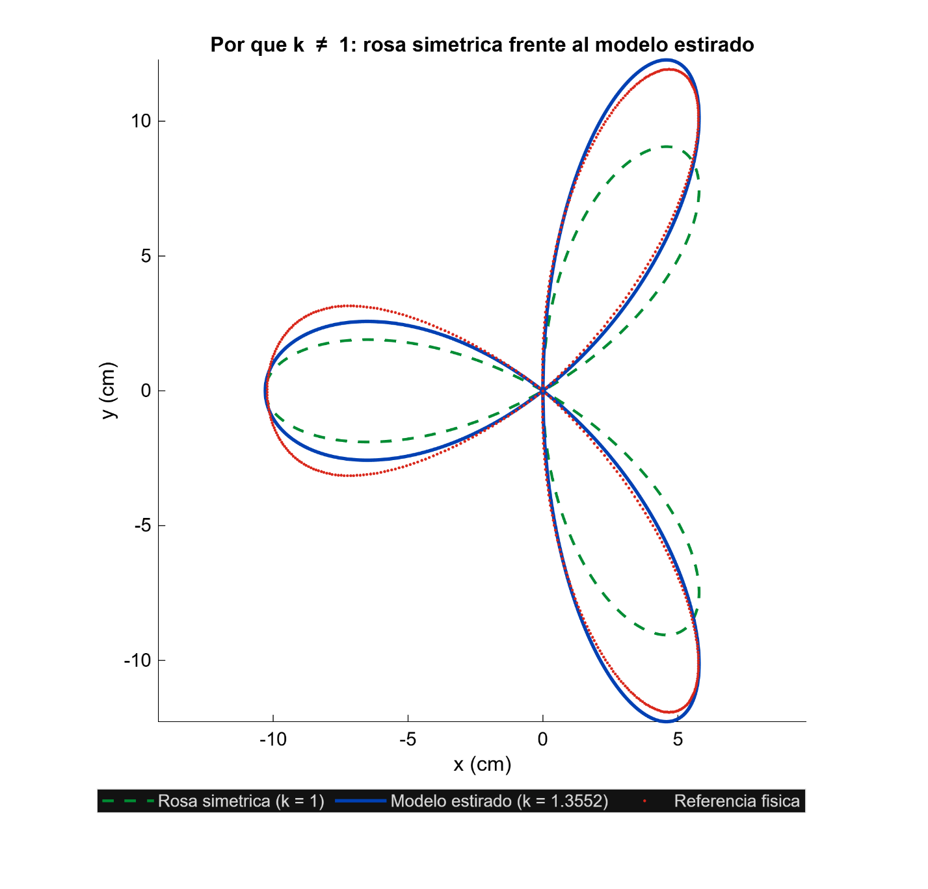
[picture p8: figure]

Figura 6. Rosa simétrica frente al modelo estirado

Comparación entre la rosa con k = 1 y el modelo con estiramiento, ambos sobre la referencia física. Justifica visualmente la necesidad del parámetro k.

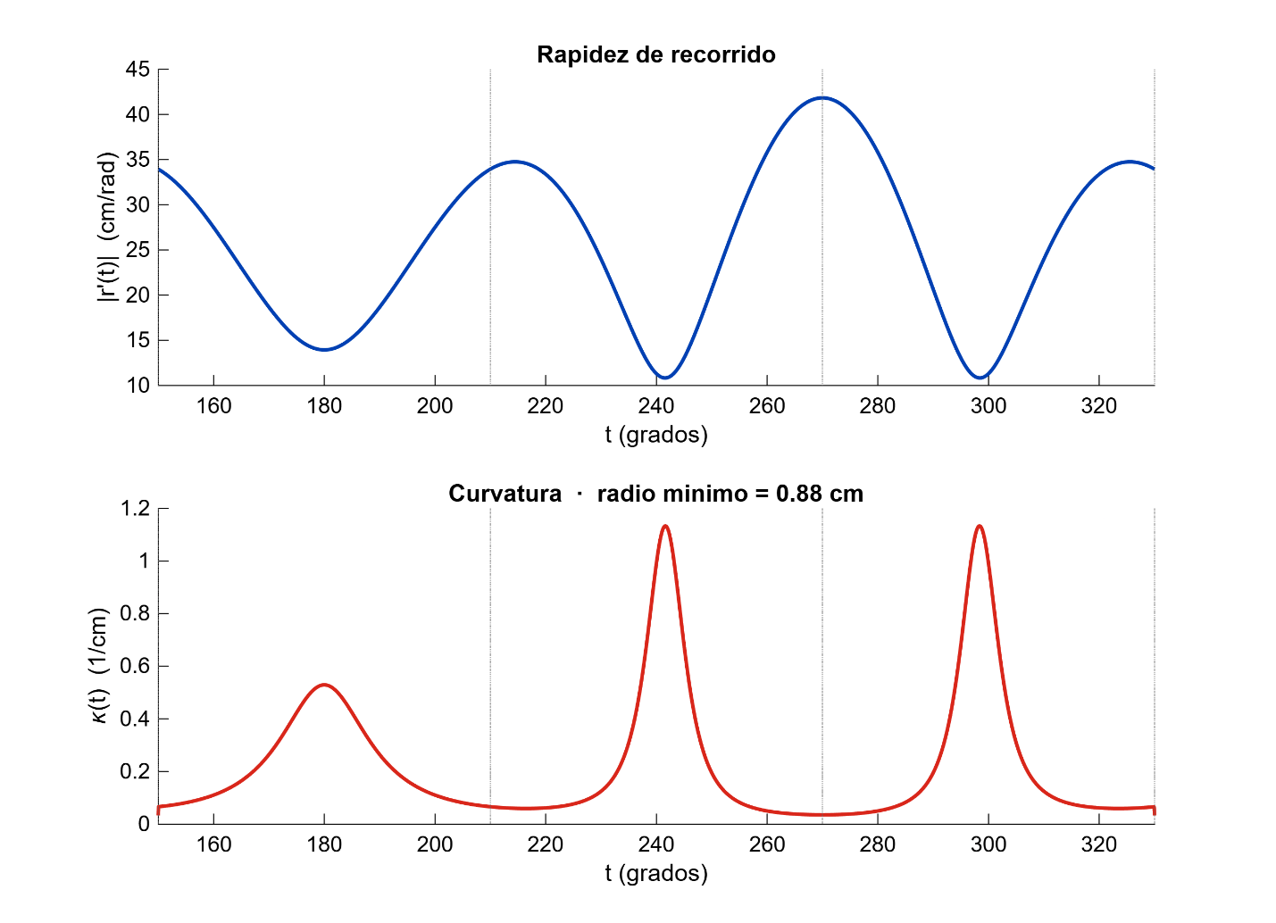
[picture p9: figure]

Figura 7. Rapidez y curvatura sobre el dominio

Perfiles de rapidez y curvatura frente al parámetro. Las líneas punteadas marcan los pasos por el origen.

# 9. Instrucciones de ejecución en MATLAB

## 9.1 Archivo principal

El archivo que debe ejecutarse es mathbot_avance1.m. Genera las seis figuras de la sección 8 y las dos de la sección 14.6, y imprime en la Command Window las tablas de validación de las secciones 10.2 y 10.3.

## 9.2 Orden de ejecución

1. Colocar mathbot_avance1.m, trayectoria_brazo.csv y wpd_datasets.csv en la misma carpeta.
2. Fijar esa carpeta como directorio de trabajo de MATLAB.
3. Ejecutar mathbot_avance1.m. No requiere argumentos ni entrada del usuario.
4. Opcional: ejecutar diagnostico_medicion.m para reproducir el análisis de la calidad de la medición citado en la sección 11.2.

Los dos archivos son independientes entre sí y pueden ejecutarse en cualquier orden.

## 9.3 Parámetros modificables

Variable | Línea | Efecto de modificarla
A | bloque 1 | Amplitud base en cm. Escala la figura completa de forma uniforme.
k | bloque 1 | Factor de anisotropía. Con k = 1 se obtiene la rosa simétrica.
n | bloque 1 | Frecuencia angular. Con n impar da n lóbulos; con n par da 2n y exige duplicar el dominio.
phi | bloque 1 | Fase en radianes. Rota la figura completa.
t0, t1 | bloque 1 | Extremos del dominio. Deben mantener una separación de π para recorrer la curva una sola vez.
outdir | encabezado | Carpeta donde se guardan los PNG. Se crea automáticamente si no existe.

## 9.4 Consideraciones

- El script usa únicamente funciones de MATLAB base. No requiere Statistics and Machine Learning Toolbox ni Optimization Toolbox.
- La exportación de figuras usa exportgraphics, disponible desde R2020a. En versiones anteriores el script recurre automáticamente a print con la misma resolución.
- trayectoria_brazo.csv debe conservar sus tres columnas con los encabezados t_index, X_cm y Y_cm, y sus 600 filas en el orden original, porque el script separa los lóbulos por bloques de 200 puntos. wpd_datasets.csv se lee con sus dos filas de encabezado y sus tres pares de columnas X,Y; el script le aplica por su cuenta la corrección de aspecto de la sección 14.3, así que debe usarse sin modificar. Si ese segundo archivo no está en la carpeta, el script omite las figuras 8 y 9 y el resto se genera igual.
- El ajuste del factor de escala tarda unos segundos. Es la única parte del script con costo apreciable.
- Si se cambia A, k o n, las cifras impresas en consola dejan de coincidir con las reportadas en la sección 10, que corresponden a los valores declarados en la sección 4.1.
- La medición sobre los píxeles del PDF de la sección 14.2 se hizo con un script aparte en Python. No forma parte de los archivos de MATLAB entregados y sus resultados se citan en el documento como dato de entrada: el script principal no lo necesita para correr.

# 10. Validación inicial del modelo

## 10.1 Métrica declarada

El enunciado del proyecto exige validar el modelo pero no define contra qué magnitud se mide el error. El equipo adopta la siguiente definición y la mantiene en los avances posteriores:

Desviación perpendicular máxima entre cada punto de la referencia física y la curva del modelo, normalizada por el radio máximo del trazo, que es de 13.16 cm.

Se elige el máximo y no el promedio porque es el criterio más exigente de los considerados. Bajo esta métrica, el objetivo interno del equipo es una desviación máxima del 5 %, equivalente a 6.58 mm.

## 10.2 Resultados

Tramo | RMS | Máximo | Máx. (% de Rmax)
Lóbulo eje X negativo | 3.86 mm | 6.53 mm | 4.96 %
Lóbulo Q1 | 1.60 mm | 3.65 mm | 2.77 %
Lóbulo Q4 | 1.60 mm | 3.65 mm | 2.77 %
Global (600 puntos) | 2.58 mm | 6.53 mm | 4.96 %

Precisión alcanzada: 95.04 % bajo la métrica declarada. El objetivo interno del 5 % se cumple, pero por un margen de 0.04 puntos, y ese margen lo consume por completo el lóbulo menor. Los dos lóbulos mayores ajustan al 2.77 %.

El contraste de descriptores geométricos de la sección 6 constituye una segunda validación, independiente de la anterior: no usa los 600 puntos sino las magnitudes medidas con regla, y las cinco diferencias caen dentro de la incertidumbre del instrumento.

## 10.3 Tercera validación: contra la imagen del enunciado

La validación de la sección 10.2 usa el trazo físico construido por el equipo. Como comprobación independiente, la curva de referencia entregada en el enunciado (Figura 1) se digitalizó por separado con WebPlotDigitizer y se contrastó contra el mismo modelo, sin reajustar ningún parámetro. Las dos fuentes no comparten instrumento, escala ni operador: una se midió con regla sobre el cartón, la otra se leyó directamente de la imagen del enunciado.

Tramo | RMS | Máximo | Máx. (% de Rmax)
Lóbulo eje X negativo | 0.48 mm | 1.00 mm | 0.76 %
Lóbulo Q1 | 0.31 mm | 0.66 mm | 0.50 %
Lóbulo Q4 | 0.72 mm | 1.19 mm | 0.90 %
Global (376 puntos) | 0.53 mm | 1.19 mm | 0.90 %

Bajo la misma métrica de la sección 10.1, la desviación máxima contra esta segunda referencia es del 0.90 % del radio máximo, frente al 4.96 % contra el trazo físico. La diferencia entre las dos cifras no viene del modelo sino de las fuentes: el trazo físico arrastra el error de construcción del cartón y el de la medición con regla, mientras que la imagen del enunciado es la curva objetivo sin intermediario mecánico. Lo que importa es que las dos referencias, tomadas de forma independiente, aceptan el mismo modelo y la misma anisotropía, y rechazan por igual una rosa simétrica: la Figura 9 lo muestra.

# 11. Diferencias, limitaciones y ajustes

## 11.1 Ajuste de escala de la digitalización

Las puntas del trazo digitalizado miden 8.850 y 11.150 cm, frente a 10 y 13 cm medidos con regla. La discrepancia es un factor común aplicado a ambas, no una diferencia de forma: la razón entre lóbulo mayor y menor es de 1.2599 en la digitalización y de 1.300 según la regla, dentro del 3 %.

Se concluye que la digitalización perdió la referencia de escala. El factor de corrección se estima por mínimos cuadrados contra el modelo y resulta de 1.1548. Deducido de forma independiente a partir de las dos medidas de regla resulta de 1.1573, con una diferencia del 0.2 % entre ambos. Ese acuerdo respalda que se trata de un problema de escala y no de forma. Todos los residuales de la sección 10.2 se calculan sobre los puntos ya corregidos.

## 11.2 Distribución no uniforme del error

El error no está repartido de forma homogénea. El lóbulo del eje X negativo concentra un residual cuadrático medio de 3.86 mm, frente a 1.60 mm en los dos mayores. La diferencia es sistemática y no ruido de medición: el residual conserva el mismo signo durante rachas de unos 75 puntos consecutivos, y la componente sistemática explica el 99.3 % de la varianza.

El ruido punto a punto de la digitalización es de 0.024 mm, unas cien veces menor que el residual del modelo. Aumentar la densidad de puntos no reduciría el error, porque el límite no lo impone el instrumento. La causa probable está en cómo se digitalizó ese tramo específico o en una imperfección del trazo físico en esa zona, y se revisará al comparar contra el trazo ejecutado por el mecanismo.

## 11.3 Limitaciones

- La incertidumbre de la medición con regla, de ±2 a 3 mm, es del mismo orden que la desviación del modelo, por lo que no permite afirmar una precisión mejor que la reportada.
- La validación es geométrica y se hace sobre el trazo de referencia. No incorpora el error mecánico del mecanismo, que se caracteriza por separado.
- El modelo se validó contra una única digitalización. No se dispone de repeticiones que permitan estimar la dispersión del proceso de captura.

## 11.4 Ajustes considerados y descartados

Se evaluaron dos variantes con un parámetro adicional que reducen el residual del lóbulo menor: un exponente de forma sobre el coseno y una modulación de la amplitud del tipo (1 + e·cos 2t). Ambas bajan la desviación máxima por debajo del 4.1 %, pero se descartaron porque agregan un parámetro sin significado geométrico identificable en la referencia, y porque ajustan una desviación cuya causa todavía no está establecida. Se prefirió mantener el modelo de cuatro parámetros, todos con interpretación directa, y reportar el residual tal como es.

# 12. Conclusión sobre la validez inicial del modelo

1. La trayectoria de referencia es una rosa polar de tres pétalos compuesta con un estiramiento afín sobre el eje Y. Una sola ecuación paramétrica continua la describe por completo, sin necesidad de definirla por tramos.
2. El dominio adoptado, de longitud π, recorre la figura exactamente una vez, y sus extremos coinciden con pasos por el origen.
3. El modelo reproduce las cinco magnitudes geométricas contrastadas dentro de la incertidumbre de la regla, y el factor de escala de la digitalización estimado por dos vías independientes coincide dentro del 0.2 %.
4. La desviación máxima frente a la referencia física es del 4.96 % del radio máximo, con un valor cuadrático medio del 1.96 %.
5. El modelo se considera válido como base para las siguientes etapas. El residual restante es sistemático y se concentra en el lóbulo menor; queda registrado como limitación conocida y se revisará al comparar contra el trazo ejecutado.

# 14. Verificación de la ecuación contra la imagen de referencia

## 14.1 Motivo de la verificación

Las secciones 1 a 12 validan el modelo contra los 600 puntos del trazo físico digitalizado por el equipo. Para comprobar que la misma ecuación reproduce además la curva que el enunciado entregó (Figura 1), esa imagen se digitalizó de forma independiente con WebPlotDigitizer, separando el trazo por colores (wpd_datasets.csv: 376 puntos, 119 en azul, 128 en magenta y 129 en verde, estos últimos en dos ramas que comparten el origen).

Evaluado contra ese dataset, el modelo de la sección 4 mostraba una desviación máxima cercana al 12 % del radio, y un reajuste sobre esos mismos puntos devolvía k = 1.098, un valor que implica tres pétalos casi iguales. Ese resultado contradice lo que se ve directamente en la Figura 1, donde los pétalos del primer y cuarto cuadrante son visiblemente más grandes que el pétalo alineado con el eje X. Esta sección resuelve la contradicción midiendo la curva sobre la imagen misma.

## 14.2 Medición directa sobre la imagen del enunciado

Para tener una referencia que no dependa de cómo se calibró el digitalizador, la curva se extrajo de los píxeles del propio PDF. La página se renderizó a 400 ppp (3400 × 4400 px) y el trazo se separó por color, obteniendo 347 543 píxeles de curva. El renderizado usa la misma resolución en X y en Y, de modo que esas coordenadas son isotrópicas por construcción: no pueden introducir una anisotropía que no esté en el dibujo.

El origen se tomó en el cruce de los ejes dibujados, en el píxel (1892.5, 2232.5). Al ajustar el modelo a esos píxeles dejando libres A, k, φ y también el origen, el ajuste lo sitúa en (1893.0, 2232.4) — a medio píxel del cruce de los ejes — lo que confirma que el punto triple de la curva coincide con el origen del sistema de coordenadas del dibujo. El renderizado del PDF, la segmentación por color y el ajuste de esta sección se programaron en Python, por la disponibilidad de librerías de procesamiento de imagen; el resto del trabajo —el modelo, las figuras y la validación de las secciones 8 y 10— está en MATLAB.

Descriptor | Imagen del PDF | Dataset crudo | Dataset corregido
Razón punta mayor / punta menor | 1.2813 | 1.0691 | 1.2860
Ángulo de la punta mayor | 67.68° | 62.74° | 67.62°

## 14.3 El error estaba en la calibración del dataset, no en la ecuación

La Figura 1 no trae escala numérica en sus ejes, así que la calibración de WebPlotDigitizer se introdujo a mano y las escalas de X y de Y no quedaron iguales. Comparando ambas fuentes, el factor entre ellas es sy/sx = 0.80: el eje Y del dataset quedó comprimido cerca de un 20 %. Multiplicando la columna Y por 1.243, el dataset recupera la razón entre pétalos de la imagen (1.286 frente a 1.281) y cae sobre la curva del modelo con un residual de 0.35 % RMS y 1.00 % máximo.

En consecuencia, los parámetros A = 12.686 y k = 1.0982 reportados en la revisión anterior de esta sección provienen de datos distorsionados y quedan descartados. El dataset sigue sirviendo para verificar la forma, pero solo después de corregir su aspecto.

## 14.4 La ecuación de la sección 4 reproduce la curva del enunciado

Residual de cada valor de k contra los píxeles extraídos de la imagen, con la escala A optimizada en cada caso:

Valor de k | RMS (% Rmax) | Máximo (% Rmax)
1.3552 · modelo del Avance 1 (sección 4.1) | 0.38 % | 1.42 %
1.3652 · ajuste libre a la imagen | 0.36 % | 1.23 %
1.0982 · ajuste al dataset distorsionado | 3.34 % | 11.51 %
1.0000 · rosa simétrica pura | 4.68 % | 14.89 %

El trazo dibujado en el PDF mide unos 9 px de ancho a 400 ppp, de modo que el piso del residual es de aproximadamente 0.22 % del radio. Los dos primeros valores de k están, en la práctica, dentro del grosor de la línea del dibujo.

El ajuste libre sobre la imagen devuelve k = 1.3652 con φ = −0.013°, y despejar k de la razón entre puntas medida da k = 1.3622. Ambos coinciden con el 1.3552 de la sección 4.1 dentro del 0.7 %, por debajo de la incertidumbre de ±2 a 3 mm de la regla declarada en la sección 11.3. El modelo original queda confirmado. Si se quiere adoptar un único valor medido sobre la imagen de referencia, corresponde k = 1.365; la diferencia con el valor en uso no es distinguible al trazar.

## 14.5 Por qué sigue siendo la misma rosa polar

La curva del proyecto es la imagen de una rosa polar simétrica bajo una transformación lineal, y ahí está la razón de que sus pétalos dejen de ser iguales sin que la ecuación deje de ser una sola expresión continua.

Se parte de la rosa r(θ) = −A·cos(3θ), que en forma paramétrica es:

u(t) = −A·cos(3t)·cos t v(t) = −A·cos(3t)·sin t

Su radio es |r| = A·|cos 3t|, que no depende de la dirección: los tres pétalos son congruentes. Las puntas se alcanzan donde cos(3t) = ±1, es decir en t = 60°, 180° y 300°, las tres a distancia A del origen. Ésa es la rosa simétrica.

El modelo aplica a esa rosa la transformación lineal T = diag(1, k), que estira el plano sobre el eje Y:

(x, y) = T(u, v) = (u, k·v)

Sustituyendo se obtienen exactamente las ecuaciones de la sección 4. La curva del proyecto es, por tanto, T aplicada a la rosa: la misma rosa polar vista a través de un estiramiento vertical.

Esto se comprueba también en forma cartesiana. La rosa r = −A·cos 3θ tiene ecuación implícita (u² + v²)² = A·u·(3v² − u²). Sustituyendo u = x y v = y/k se llega a:

(x² + y²/k²)² = A·x·(3y²/k² − x²)

que es exactamente la forma implícita reportada en la sección 7.4. El cambio de variable v = y/k deshace el estiramiento: la curva del proyecto y la rosa simétrica son la misma curva escrita en dos sistemas de coordenadas relacionados por T.

El efecto de T sobre cada pétalo explica la asimetría observada. La punta del pétalo alineado con el eje X está en t = 180°, en el punto (−A, 0); como su ordenada es cero, T la deja fija y ese pétalo no se alarga. Las puntas de los otros dos están en t = 240° y t = 300°, en (A/2, ∓(√3/2)·A), y T las lleva a (A/2, ∓(√3/2)·A·k). De ahí salen las dos relaciones que gobiernan la forma:

ρ = (punta mayor) / (punta menor) = √(1 + 3k²) / 2 tan ψ = √3 · k

Para k > 1 se cumple ρ > 1: los pétalos del primer y cuarto cuadrante son estrictamente más largos que el del eje X, y sus puntas se abren desde 60° hacia el eje Y. Con k = 1.365 las fórmulas dan ρ = 1.284 y ψ = 67.1°, frente a 1.281 y 67.7° medidos sobre la imagen. Invirtiendo la primera relación, k = √((4ρ² − 1)/3), la razón medida de 1.2813 devuelve k = 1.3622.

La transformación no cambia la naturaleza de la curva: T es lineal e invertible (det T = k ≠ 0), de modo que la imagen sigue siendo una curva algebraica de grado cuatro, cerrada, con un único punto triple en el origen. Los pasos por el origen siguen ocurriendo donde cos(3t) = 0, y las tres tangentes en ese punto tienen pendientes +k/√3, −k/√3 e infinita: para k = 1 quedan separadas 60° entre sí y, al crecer k, se cierran hasta 51.8° con k = 1.365. La asimetría que se observa —pétalos mayores en Q1 y Q4, pétalo menor sobre el eje X— es exactamente el efecto de k > 1 sobre una rosa de tres pétalos, y k es el único parámetro que la gobierna.

## 14.6 Comparación visual

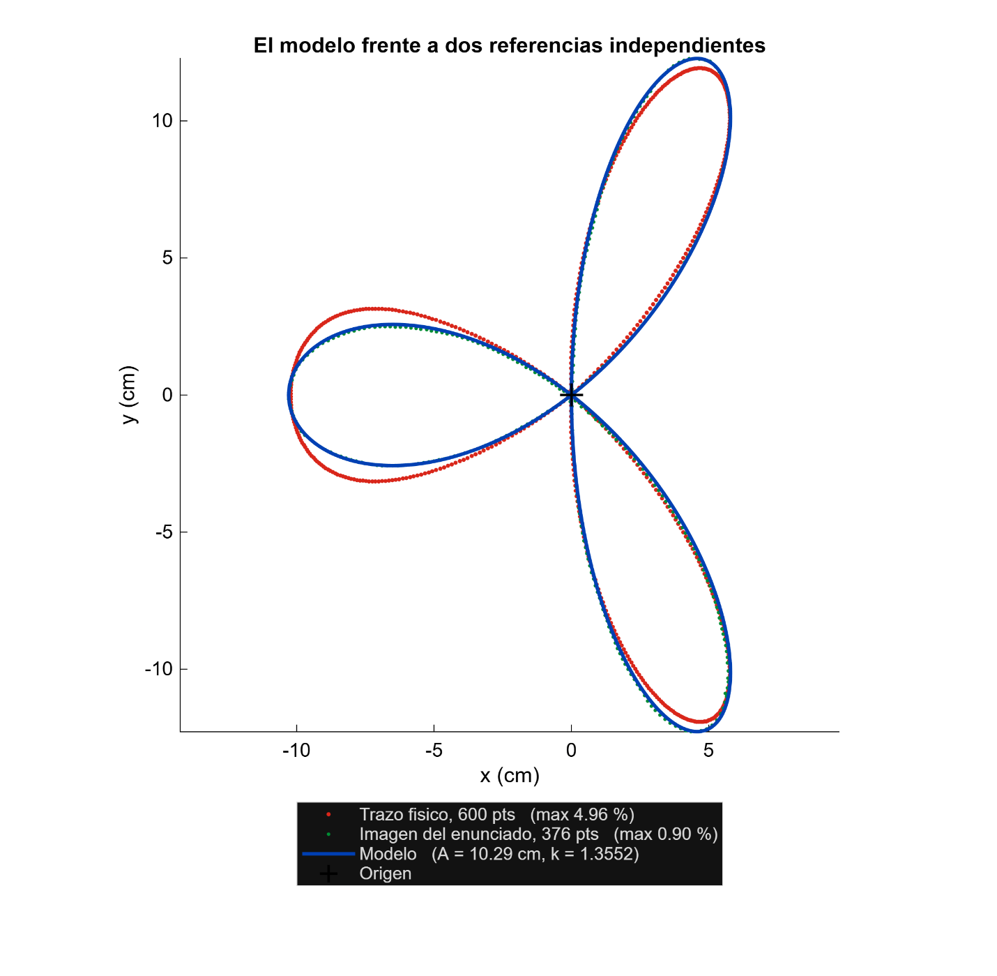
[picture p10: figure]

Figura 8. El modelo frente a las dos referencias independientes: el trazo físico y la imagen del enunciado

La figura superpone el modelo sobre las dos referencias medidas de forma independiente: el trazo físico aporta 600 puntos y la imagen del enunciado 376, y ambas caen sobre la misma curva. Los dos conjuntos se llevan a la escala del modelo alineando la punta del pétalo menor, que vale exactamente A y no depende de k.

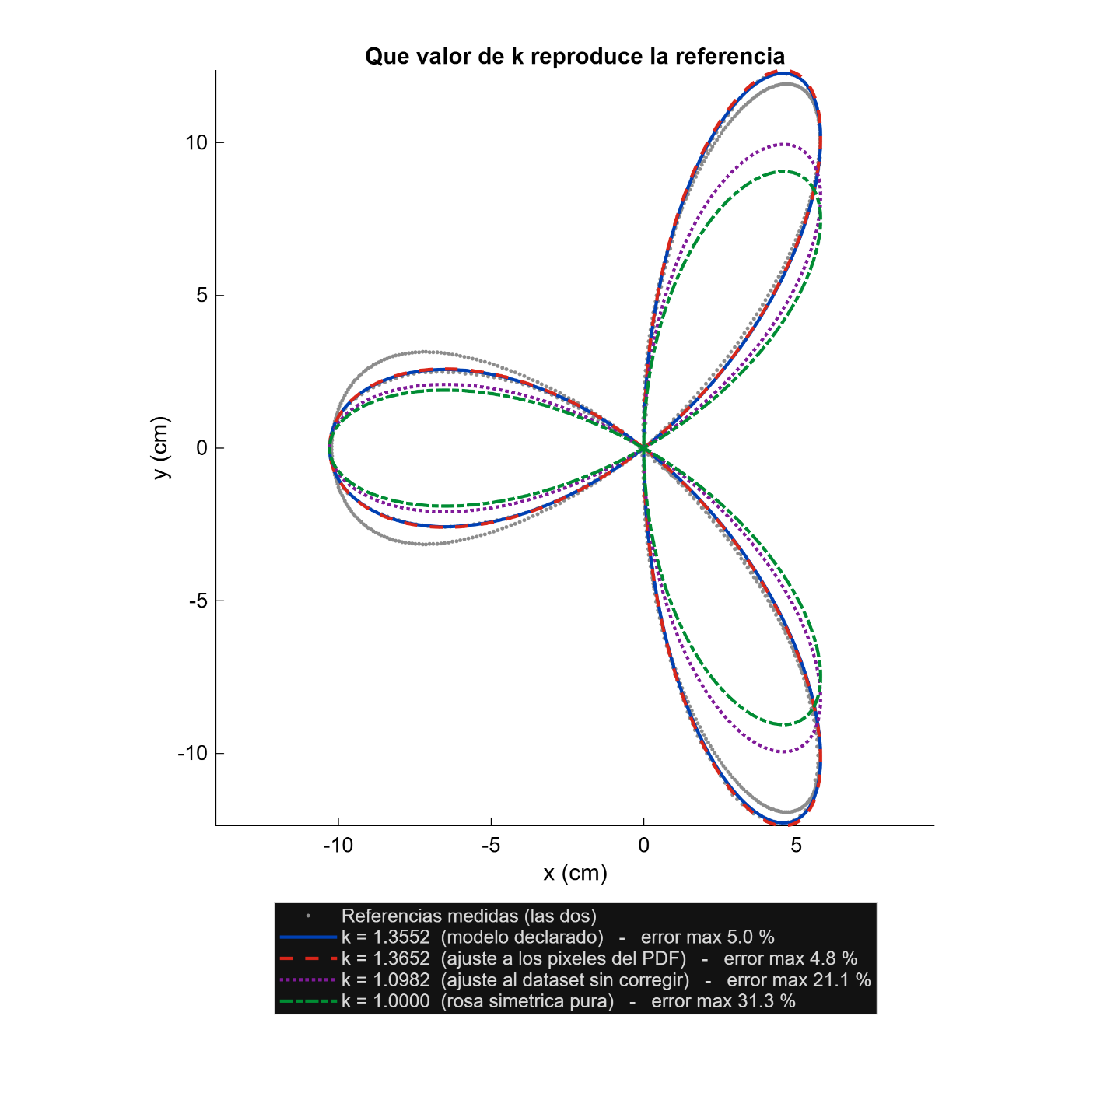
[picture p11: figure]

Figura 9. Qué valor de k reproduce la referencia: cuatro anisotropías contra las dos fuentes medidas

La Figura 9 mantiene A fija en las cuatro curvas, de modo que todas quedan ancladas en la punta del pétalo menor y lo único que las diferencia es cuánto se alargan los otros dos: es una comparación de forma, no de tamaño. Los dos valores compatibles con las referencias, 1.3552 y 1.3652, quedan sobre los puntos medidos; el ajuste al dataset sin corregir, 1.0982, y la rosa simétrica pura, 1.0000, se apartan visiblemente en los tres pétalos.

## 14.7 Conclusión de la verificación

1. La curva de referencia no es una rosa simétrica. Los pétalos del primer y cuarto cuadrante son un 28 % más largos que el pétalo del eje X (razón medida 1.2813), y esa desigualdad es precisamente lo que introduce el factor k del modelo.
2. La ecuación de la sección 4, con la anisotropía de la sección 4.1, reproduce la curva del enunciado con una desviación máxima del 1.42 % del radio, dentro del ancho del trazo del propio dibujo.
3. La discrepancia detectada en la revisión anterior era un error de calibración del dataset digitalizado, no del modelo: el eje Y estaba comprimido un 20 %. Corregido el aspecto, las tres fuentes coinciden.
4. No hay que cambiar de familia de curva ni reajustar los parámetros de fabricación: A = 10.29 cm y k = 1.3552 se mantienen. Opcionalmente puede adoptarse k = 1.365, el valor medido sobre la imagen de referencia.

# 15. Anexos

Archivo | Contenido
mathbot_avance1.m | Archivo principal. Define el modelo, lee las dos referencias, calcula los residuales y genera las ocho figuras del documento: las seis de la sección 8 y las dos de la sección 14.6.
diagnostico_medicion.m | Análisis de la calidad de la medición: separa la componente sistemática de la aleatoria del residual. Sustenta la sección 11.2.
trayectoria_brazo.csv | Referencia física digitalizada. 600 puntos en coordenadas cartesianas, tres tramos de 200.
wpd_datasets.csv | Referencia de la Figura 1 digitalizada de forma independiente con WebPlotDigitizer (3 datasets por color). Se usa sin modificar: el script aplica por su cuenta la corrección del eje Y de la sección 14.3.

MATHBOT · Entregable 1 · 1

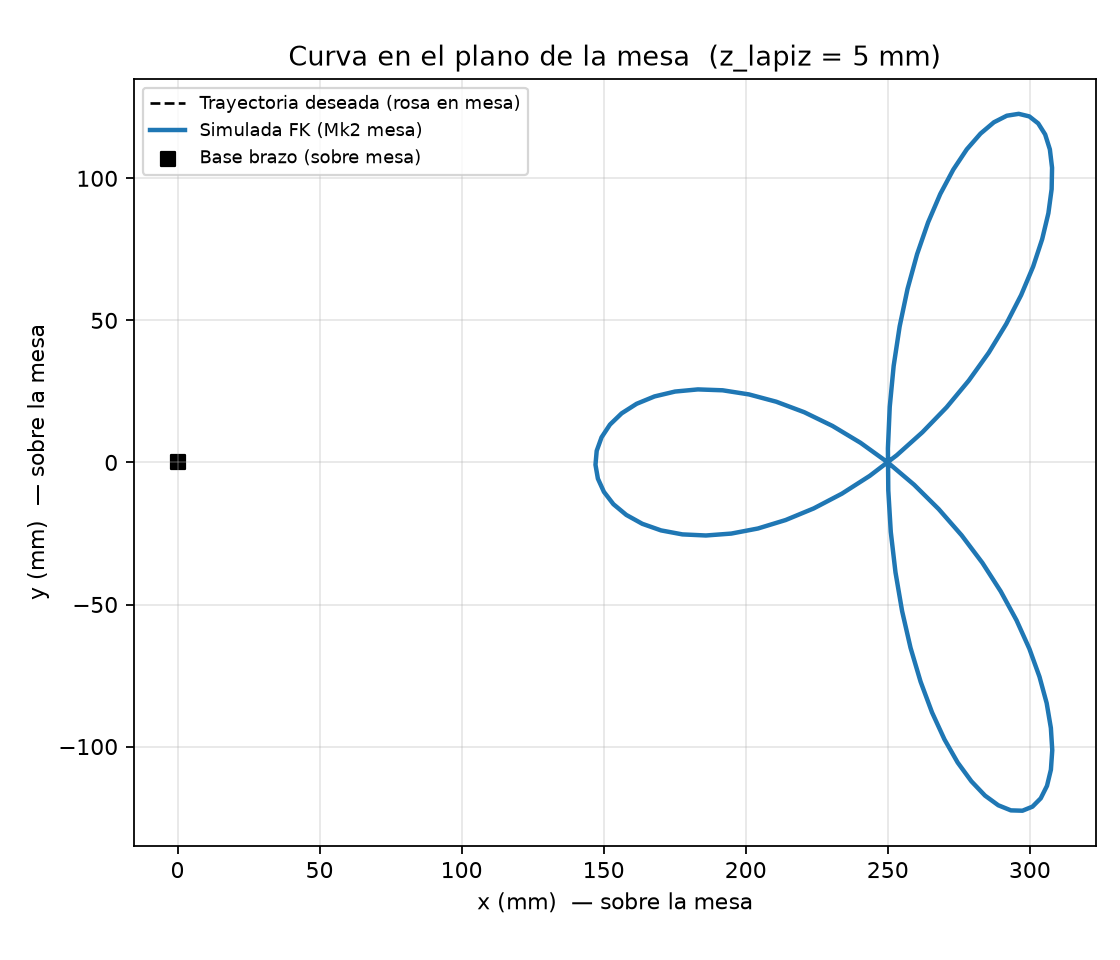
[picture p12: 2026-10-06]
python/figuras/eezy_trayectoria_xy.png

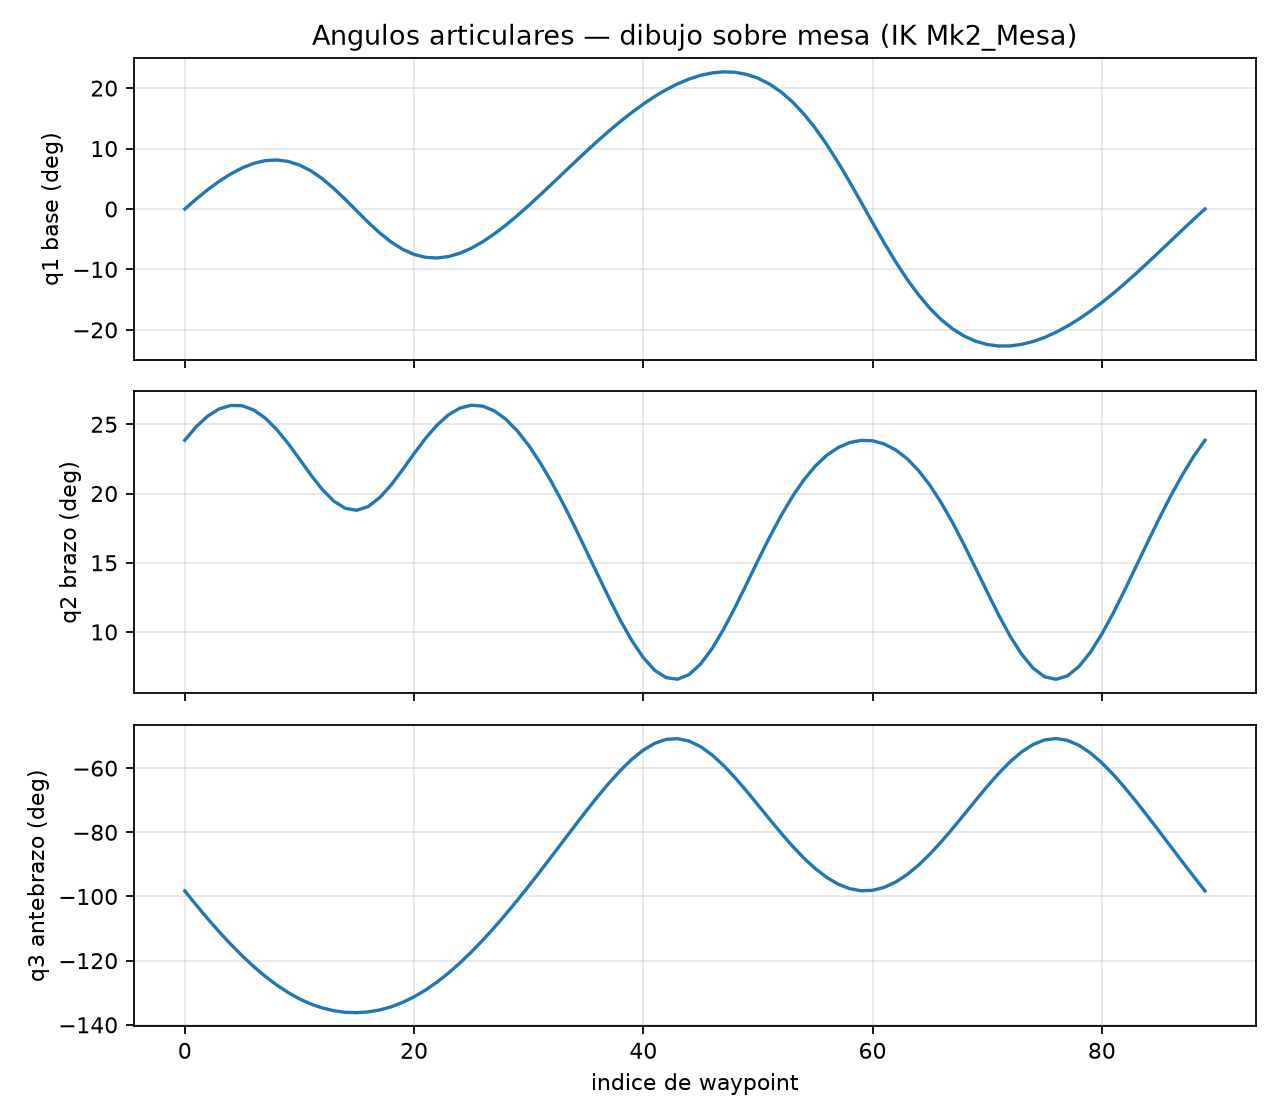
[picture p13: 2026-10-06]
python/figuras/eezy_angulos.png

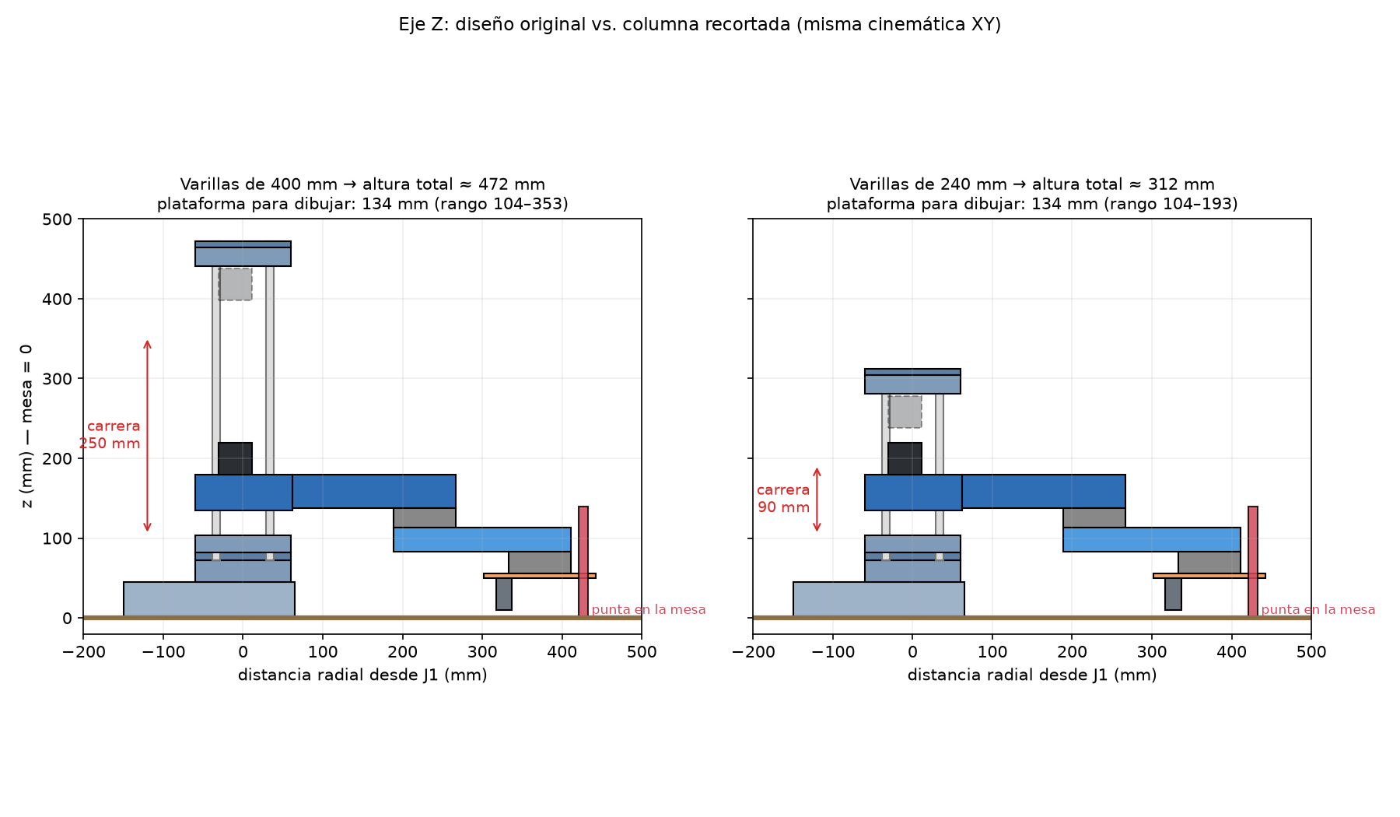
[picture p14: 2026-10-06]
python/figuras/scara_pila_z.png

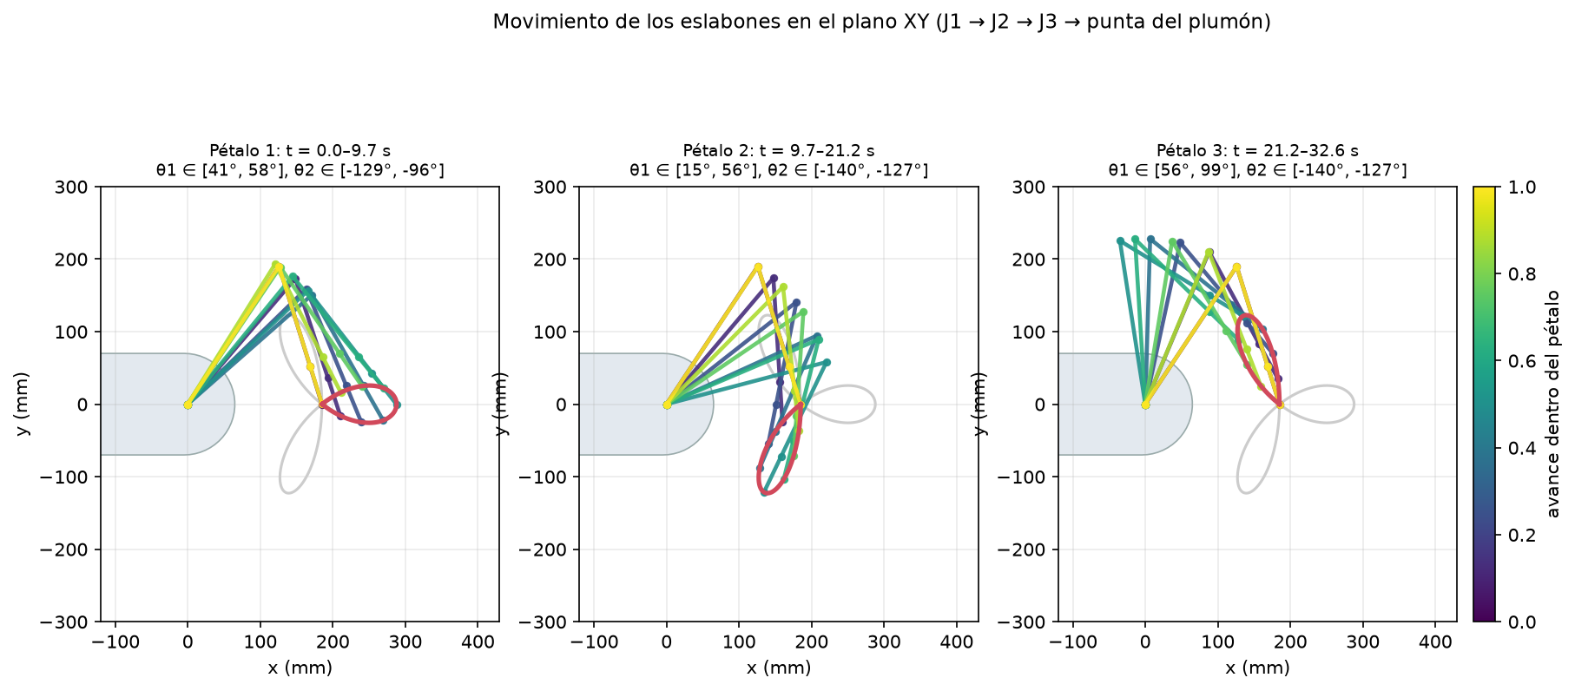
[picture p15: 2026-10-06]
python/figuras/scara_eslabones_xy.png

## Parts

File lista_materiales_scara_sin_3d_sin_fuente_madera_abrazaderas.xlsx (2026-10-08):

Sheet: Lista de materiales
LISTA DE MATERIALES - ROBOT SCARA (SIN PIEZAS IMPRESAS 3D)
Fuente | Artículo y transcript de HowToMechatronics
Criterio | Excluidas todas las piezas STL/impresas en 3D: brazos, poleas impresas, soportes, carcasas, cubiertas y piezas del gripper.
Categoría | Material | Cantidad | Especificación | Uso / ubicación | Notas
Electrónica | Motor NEMA 17 | 4 | 1.8°, compatible con A4988 | J1, J2, J3 y Z | El de J3 puede ser el corto de 24 mm
Electrónica | Driver A4988 con disipador | 4 | Uno por motor
Electrónica | Arduino Mega 2560 | 1 | Clon con CH340 sirve |  | El firmware usa los pines extra del Mega (ver firmware/README.md)
Electrónica | Arduino CNC Shield | 1 | Formato UNO, se monta sobre el Mega
Electrónica | Servo MG996R | 1 | Alto torque | Pinza | No aplica con el cabezal de disco: se reemplaza por un micro servo SG90 (levante del plumón)
Electrónica | Micro-switch final de carrera | 4 | Tipo palanca/roller
Electrónica | Jumpers | 1 | Para configurar microstepping | Paquete surtido
Electrónica | Cableado | 1 | Motores, switches y servo | Según montaje
Transmisión | Varilla lisa de acero | 4 | 10 mm x 400 mm | Rodamientos lineales
Transmisión | Husillo / lead screw | 1 | 8 mm x 400 mm | Se puede cortar a 380 mm
Transmisión | Tuerca del husillo | 1 | Compatible con husillo de 8 mm
Transmisión | Acople flexible | 1 | 5 mm a 8 mm | Motor Z a husillo
Rodamientos | Rodamiento lineal LM10UU | 4 | 10 x 19 x 29 mm
Rodamientos | Rodamiento axial 51108 | 2 | 40 x 60 x 13 mm | J1: uno a cada lado de la base
Rodamientos | Rodamiento axial 51107 | 4 | 35 x 52 x 12 mm | J2 y J3: uno arriba y otro abajo de cada brazo | La lista del artículo dice 2, pero el ensamble y el STEP usan 4
Rodamientos | Rodamiento radial 6807-2RS (61807) | 1 | 35 x 47 x 7 mm | Primera articulación | No aparece en la lista del artículo; el texto lo monta primero en la base
Rodamientos | Rodamiento radial 6806-2RS (61806) | 2 | 30 x 42 x 7 mm | J2 y J3: uno dentro de cada brazo
Rodamientos | Rodamiento 608 / 608-2RS | 5 | 8 x 22 x 7 mm | 2 polea intermedia J1, 2 polea intermedia J2, 1 husillo Z
Correas | Correa GT2 cerrada | 1 | 200 mm x 6 mm
Correas | Correa GT2 cerrada | 2 | 300 mm x 6 mm
Correas | Correa GT2 cerrada | 2 | 400 mm x 6 mm
Tornillería | Pernos y tuercas M3/M4/M5 | 1 | Varias longitudes | Comprar surtido
Tornillería | Tuercas autoblocantes y arandelas | 1 | Para M3/M4/M5/M8
Tornillería | Perno M4 | 4 | 55 mm | Primera articulación
Tornillería | Perno M8 | 1 | 45 mm + arandela + tuerca | Polea intermedia
Tornillería | Perno M3 | 1 | 20 mm + tuerca | Micro-switches
Tornillería | Perno M5 | 4 | 25 mm | Unión de brazos
Tornillería | Perno M4 | 6 | 20 mm | Segunda articulación
Tornillería | Perno M5 | 1 | 35 mm + tuercas | Tensor de correa
Gripper | Varilla lisa | 2 | 6 mm | Guías de pinza | No aplica con el cabezal de disco
Gripper | Servo horn | 1 | Compatible con MG996R |  | No aplica con el cabezal de disco
Gripper | Cable de 3 conductores | 1 | Para servo |  | No aplica con el cabezal de disco
Base | Pernos de cabeza plana | 1 | Para fijar la base
Cableado | Malla/funda para cables | 1 | Longitud según montaje | Opcional
Cableado | Cinchos | 1 | Paquete

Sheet: Excluido por ser 3D
Piezas excluidas | Motivo
Base plástica | Se fabrica mediante impresión 3D
Brazos | Se fabrica mediante impresión 3D
Poleas GT2 impresas | Se fabrica mediante impresión 3D
Soportes de motores y rodamientos | Se fabrica mediante impresión 3D
Soportes de varillas | Se fabrica mediante impresión 3D
Carcasas y cubiertas | Se fabrica mediante impresión 3D
Piezas del gripper | Se fabrica mediante impresión 3D
Sujetadores plásticos | Se fabrica mediante impresión 3D
Soporte de Arduino/CNC Shield | Se fabrica mediante impresión 3D

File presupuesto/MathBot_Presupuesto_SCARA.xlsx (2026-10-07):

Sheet: Resumen
Presupuesto · SCARA MathBot
SCARA de HowToMechatronics con columna Z recortada y cabezal de disco (versión final): plumón, electroimán y sensor inductivo. Precios locales de Electrónica 2001 y Steren verificados en línea el 06-oct-2026; el resto, cotizar o estimado. Amazon con impuestos y casillero.
Indicadores
Presupuesto del equipo |  | $300.00 | ← editar en Supuestos
Gastado a la fecha |  | $0.00
Pendiente por comprar |  | $238.73
Contingencia sobre lo pendiente |  | $23.87
Proyección final (con contingencia) |  | $262.60
Presupuesto restante |  | $37.40 | Dentro del presupuesto
Uso del presupuesto |  | 87.5%
Costo por integrante |  | $65.65
Ahorro por lo que ya tenemos |  | $147.40
Pendiente si todo se compra donde sale más barato |  | $208.37 | ← supone que las tiendas 'Cotizar' tienen el producto al precio estimado
Ahorro potencial (eligiendo siempre lo más barato) |  | $30.35
Por categoría
Categoría | Estimado | Ya lo tenemos | Gastado | Pendiente | Proyección | % del total
Estructura y eje Z | $71.85 | $6.00 | $0.00 | $65.85 | $65.85 | 27.6%
Rodamientos | $62.91 | $0.00 | $0.00 | $62.91 | $62.91 | 26.4%
Transmisión | $31.12 | $0.00 | $0.00 | $31.12 | $31.12 | 13.0%
Motores y electrónica | $112.50 | $97.82 | $0.00 | $14.68 | $14.68 | 6.1%
Cabezal de disco | $28.66 | $0.00 | $0.00 | $28.66 | $28.66 | 12.0%
Electrónica MathBot | $7.88 | $0.00 | $0.00 | $7.88 | $7.88 | 3.3%
Tornillería | $20.14 | $0.00 | $0.00 | $20.14 | $20.14 | 8.4%
Impresión y varios | $51.07 | $43.58 | $0.00 | $7.49 | $7.49 | 3.1%
Total | $386.12 | $147.40 | $0.00 | $238.73 | $238.73 | 100.0%
Por fuente (lo que falta comprar) |  |  |  | Por prioridad
Fuente | Pendiente | Proyección |  | Prioridad | Pendiente | Proyección
Local | $66.98 | $66.98 |  | Obligatorio | $221.74 | $221.74
Amazon | $171.75 | $171.75 |  | Recomendado | $16.98 | $16.98
 |  |  |  | Opcional | $0.00 | $0.00
Valor en factura Amazon por comprar (USD) |  | $128.92
Valor por envío (según número de envíos) |  | $128.92 |  | Los opcionales empiezan en 'No comprar': no suman hasta que cambien su estado.
Cada envío queda bajo USD 300: solo pagan 13 % de IVA en aduana.
Pagado por integrante
Integrante | Pagado | Le toca (proyección / integrantes) | Diferencia
Integrante 1 | $0.00 | $65.65 | -$65.65
Integrante 2 | $0.00 | $65.65 | -$65.65
Integrante 3 | $0.00 | $65.65 | -$65.65
Integrante 4 | $0.00 | $65.65 | -$65.65
Diferencia positiva = ha puesto más de lo que le toca.
Cómo usarlo
1. En Supuestos: presupuesto, nombres del equipo, número de envíos del casillero.
2. En Lista de materiales marquen el Estado de cada fila: 'Ya lo tenemos' (no se compra), 'Cotizado' (actualicen el precio local), 'Comprado'.
3. Cambien 'Fuente elegida' a Local o Amazon; si se pinta naranja, la otra opción sale más barata.
4. Cada pago va a Registro de gastos con el ID del ítem: el resumen y 'Gastado real' se actualizan solos.
5. En Impresión 3D marquen las piezas impresas; los rollos de filamento a comprar salen de ahí.

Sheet: Lista de materiales
Lista de materiales · SCARA MathBot (HowToMechatronics + cabezal de disco)
Editables (amarillo, texto azul): cantidad, precios, fuente elegida, estado y responsable. Negro = fórmula. Verde = viene de otra hoja. 'Total Amazon puesto en SV' incluye impuesto de EE. UU., flete del casillero e IVA de aduana (ver Supuestos). Precios consultados el 06-oct-2026.
ID | Categoría | Componente | Especificación / modelo | Uso en el robot | Origen | Cant. | Prioridad | Tienda local sugerida | Precio local (USD/paq.) | Unid./paq. local | Precio local: verificación | Precio Amazon (USD/paq.) | Unid./paq. Amazon | Peso paq. (lb) | Total local (USD) | Total Amazon puesto en SV (USD) | Opción más barata | Fuente elegida | Costo estimado (USD) | Estado | Gastado real (USD) | Pendiente (USD) | Proyección (USD) | Responsable | Enlace Amazon | Notas / fuente del precio | Valor factura Amazon (USD) | Opción más barata (USD)
MEC-01 | Estructura y eje Z | Varilla lisa Ø10 mm | Acero endurecido, 300 mm (cortar) | 4 guías de la columna Z | HTM | 4 | Obligatorio | Creativo 3D (repuestos de impresoras) | $8.00 | 1 | Cotizar (estimado) | $17.99 | 4 | 1.80 | $32.00 | $26.94 | Amazon | Amazon | $26.94 | Por comprar | $0.00 | $26.94 | $26.94 |  | https://www.amazon.com/dp/B0D2312R72 | HTM usa 400 mm. Con el cabezal de disco bastan 240 mm (NEMA estándar en J2) o 220 mm (NEMA corto): comprar 300 y cortar. | $17.99 | $26.94
MEC-02 | Estructura y eje Z | Rodamiento lineal LM10UU | 10 × 19 × 29 mm | Plataforma Z (desliza en las varillas) | HTM | 4 | Obligatorio | Creativo 3D / CEROSA | $3.00 | 1 | Cotizar (estimado) | $7.49 | 4 | 0.25 | $12.00 | $9.81 | Amazon | Amazon | $9.81 | Por comprar | $0.00 | $9.81 | $9.81 |  | https://www.amazon.com/dp/B0D5BHVY9W |  | $7.49 | $9.81
MEC-03 | Estructura y eje Z | Husillo T8 con tuerca de latón | Tr8×8, 300 mm (avance 8 mm/rev) | Eje Z | HTM | 1 | Obligatorio | Creativo 3D | $15.00 | 1 | Cotizar (estimado) | $11.99 | 2 | 0.60 | $15.00 | $16.26 | Local | Amazon | $16.26 | Por comprar | $0.00 | $16.26 | $16.26 |  | https://www.amazon.com/dp/B08JPPC1TZ | HTM lo corta a 380 mm para varillas de 400; con varillas de 240 mm cortar a ≈225 mm. El paquete trae 2. | $11.99 | $15.00
MEC-04 | Estructura y eje Z | Acople flexible 5 → 8 mm | Aluminio | Motor Z → husillo | HTM | 1 | Obligatorio | Creativo 3D | $5.00 | 1 | Cotizar (estimado) | $9.99 | 5 | 0.25 | $5.00 | $12.84 | Local | Amazon | $12.84 | Por comprar | $0.00 | $12.84 | $12.84 |  | https://www.amazon.com/dp/B07JL1QYLS |  | $9.99 | $5.00
MEC-05 | Estructura y eje Z | Base de madera o MDF 18–20 mm | ≈ 30 × 25 cm | Fijar la base del robot (12 agujeros) | HTM | 1 | Recomendado | Almacenes Vidrí | $6.00 | 1 | Estimado |  |  |  | $6.00 |  | Local | Local | $6.00 | Ya lo tenemos | $0.00 | $0.00 | $0.00 |  |  | La consiguen sin costo. El artículo atornilla la base a madera de 20 mm y la sujeta a la mesa con prensas. | $0.00 | $6.00
ROD-01 | Rodamientos | Rodamiento axial 51108 | 40 × 60 × 13 mm | J1 (uno a cada lado de la base) | HTM | 2 | Obligatorio | CEROSA / RODASA / REPSA | $6.00 | 1 | Cotizar (estimado) | $9.99 | 2 | 0.45 | $12.00 | $13.41 | Local | Amazon | $13.41 | Por comprar | $0.00 | $13.41 | $13.41 |  | https://www.amazon.com/dp/B0FDKPGXQ4 | La lista del artículo dice 1, pero el ensamble usa 2. | $9.99 | $12.00
ROD-02 | Rodamientos | Rodamiento axial 51107 | 35 × 52 × 12 mm | J2 y J3 (2 por junta) | HTM | 4 | Obligatorio | CEROSA / RODASA / REPSA | $5.00 | 1 | Cotizar (estimado) | $10.99 | 3 | 0.45 | $20.00 | $29.25 | Local | Amazon | $29.25 | Por comprar | $0.00 | $29.25 | $29.25 |  | https://www.amazon.com/s?k=51107+thrust+ball+bearing | La lista del artículo pide 2 (solo J2); J3 usa el mismo esquema. Paquete de 3 en Amazon. | $21.98 | $20.00
ROD-03 | Rodamientos | Rodamiento radial 6807-2RS | 35 × 47 × 7 mm (pared delgada) | J1 | HTM | 1 | Obligatorio | CEROSA / RODASA / REPSA | $5.00 | 1 | Cotizar (estimado) | $7.29 | 1 | 0.10 | $5.00 | $9.14 | Local | Local | $5.00 | Por comprar | $0.00 | $5.00 | $5.00 |  | https://www.amazon.com/dp/B07RP6RDYL | No aparece en la lista del artículo, pero el texto lo instala primero en la base. | $0.00 | $5.00
ROD-04 | Rodamientos | Rodamiento radial 6806-2RS (61806) | 30 × 42 × 7 mm (pared delgada) | J2 y J3 | HTM | 2 | Obligatorio | CEROSA / RODASA / REPSA | $4.50 | 1 | Cotizar (estimado) | $13.99 | 10 | 0.50 | $9.00 | $18.41 | Local | Local | $9.00 | Por comprar | $0.00 | $9.00 | $9.00 |  | https://www.amazon.com/dp/B09D33QXFL | Amazon solo lo vende en paquete de 10. | $0.00 | $9.00
ROD-05 | Rodamientos | Rodamiento 608ZZ | 8 × 22 × 7 mm | Poleas intermedias de J1 y J2 (2 c/u) + husillo | HTM | 5 | Obligatorio | CEROSA / REPSA | $1.25 | 1 | Estimado (hay en el país) | $5.19 | 10 | 0.35 | $6.25 | $7.29 | Local | Local | $6.25 | Por comprar | $0.00 | $6.25 | $6.25 |  | https://www.amazon.com/dp/B0GYVYQKQ4 |  | $0.00 | $6.25
TRA-01 | Transmisión | Correa GT2 cerrada 200 mm | Ancho 6 mm, paso 2 mm | J1 etapa 1 (motor → 80 dientes) | HTM | 1 | Obligatorio | Creativo 3D | $4.00 | 1 | Cotizar (estimado) | $6.92 | 5 | 0.10 | $4.00 | $8.69 | Local | Amazon | $8.69 | Por comprar | $0.00 | $8.69 | $8.69 |  | https://www.amazon.com/dp/B0FRDL4X1Z |  | $6.92 | $4.00
TRA-02 | Transmisión | Correa GT2 cerrada 300 mm | Ancho 6 mm, paso 2 mm | J1 etapa 2 y J2 etapa 2 | HTM | 2 | Obligatorio | Creativo 3D | $4.00 | 1 | Cotizar (estimado) | $8.79 | 4 | 0.10 | $8.00 | $10.96 | Local | Amazon | $10.96 | Por comprar | $0.00 | $10.96 | $10.96 |  | https://www.amazon.com/dp/B0CN41SWMZ |  | $8.79 | $8.00
TRA-03 | Transmisión | Correa GT2 cerrada 400 mm | Ancho 6 mm, paso 2 mm | J2 etapa 1 y J3 | HTM | 2 | Obligatorio | Creativo 3D | $4.50 | 1 | Cotizar (estimado) | $9.21 | 5 | 0.10 | $9.00 | $11.47 | Local | Amazon | $11.47 | Por comprar | $0.00 | $11.47 | $11.47 |  | https://www.amazon.com/dp/B0FRD6MX8J | Las poleas GT2 (110, 92, 90, 22-80, 23-80 y 20 dientes) se imprimen: ver hoja Impresión 3D. | $9.21 | $9.00
ELE-01 | Motores y electrónica | Motor paso a paso NEMA 17, 40 mm | 45 N·cm, 2 A, 1.8°, 4 cables (17HS4401) | J1, J2 y Z | HTM | 3 | Obligatorio | Electrónica 2001 (código 04-355) | $12.00 | 1 | Verificado en línea 06-oct-2026 | $13.99 | 1 | 0.75 | $36.00 | $57.35 | Local | Local | $36.00 | Ya lo tenemos | $0.00 | $0.00 | $0.00 |  | https://www.amazon.com/dp/B00PNEQI7W | Prestados. Si usan el NEMA corto también en J2 (varillas de 220 mm), bajar a 2 y subir ELE-02 a 2. Confirmar que trae cable. | $0.00 | $36.00
ELE-02 | Motores y electrónica | Motor NEMA 17 corto (pancake) | ≈ 23 mm, 17 N·cm, 1 A | J3 (aligera el brazo 2) | HTM | 1 | Obligatorio | Electrónica 2001 (preguntar) |  |  |  | $10.50 | 1 | 0.45 |  | $14.03 | Amazon | Amazon | $14.03 | Ya lo tenemos | $0.00 | $0.00 | $0.00 |  | https://www.amazon.com/dp/B0B93PNYCP | Prestado: si es de 40 mm también sirve en J3 (pesa más en el brazo 2). El artículo usa un NEMA 17 de 24 mm en J3. Si no lo consiguen, sirve uno de 40 mm (más peso en el brazo 2). | $0.00 | $14.03
ELE-03 | Motores y electrónica | CNC Shield V3 + 4 drivers A4988 | Con disipadores y jumpers | Control de los 4 motores | HTM | 1 | Obligatorio | ArduStore SV / Casa Rivas (preguntar) | $18.00 | 1 | Cotizar (estimado) | $9.99 | 1 | 0.25 | $13.50 | $12.84 | Amazon | Amazon | $12.84 | Ya lo tenemos | $0.00 | $0.00 | $0.00 |  | https://www.amazon.com/dp/B07TT3C3HB | Jumpers en ¼ de paso, como en el artículo. | $0.00 | $12.84
ELE-04 | Motores y electrónica | Drivers A4988 de repuesto | Paquete de 5 con disipador | Reemplazo si se quema uno | MathBot | 5 | Opcional |  |  |  |  | $10.19 | 5 | 0.10 |  | $12.66 | Amazon | Amazon | $12.66 | No comprar | $0.00 | $0.00 | $0.00 |  | https://www.amazon.com/dp/B07BND65C8 |  | $0.00 | $12.66
ELE-05 | Motores y electrónica | Arduino UNO R3 (compatible) | ATmega328P | Cerebro del robot | HTM | 1 | Obligatorio | Steren (ARD-010) | $8.99 | 1 | Verificado en línea 06-oct-2026 | $9.49 | 1 | 0.15 | $8.99 | $11.95 | Local | Local | $8.99 | Ya lo tenemos | $0.00 | $0.00 | $0.00 |  | https://www.amazon.com/dp/B0B6VV7MS7 | Prestado. Steren la vende como 'Placa de desarrollo ARD-010': confirmar en tienda que sea compatible con UNO. | $0.00 | $8.99
ELE-06 | Motores y electrónica | Fuente de 12 V | Mín. 4 A; el artículo sugiere 6 A | Alimentación general | HTM | 1 | Obligatorio | Steren (ELI-1260, 12 V 5 A) | $25.00 | 1 | Verificado en línea 06-oct-2026 | $15.99 | 1 | 0.90 | $25.00 | $21.97 | Amazon | Amazon | $21.97 | Ya lo tenemos | $0.00 | $0.00 | $0.00 |  | https://www.amazon.com/dp/B082PCR5YS | Usarán una fuente propia: confirmar que da 12 V y al menos 4 A (mejor 5 A con electroimán y servo). Amazon: ALITOVE 12 V 6 A. Steren también tiene la ELI-F3012 (12 V 30 A, USD 27.99), que es abierta y hay que cablear a 120 V. | $0.00 | $21.97
ELE-07 | Motores y electrónica | Final de carrera (micro switch con palanca) |  | Homing de J1, J2, J3 y Z | HTM | 4 | Obligatorio | Steren (SS0501A) | $0.75 | 1 | Verificado en línea 06-oct-2026 | $5.99 | 10 | 0.15 | $3.00 | $7.70 | Local | Local | $3.00 | Por comprar | $0.00 | $3.00 | $3.00 |  | https://www.amazon.com/dp/B07X142VGC |  | $0.00 | $3.00
ELE-08 | Motores y electrónica | Cables de motor de 1 m | XH2.54 de 4 pines, paquete de 4 | Llevar los motores hasta la CNC Shield | HTM | 4 | Recomendado |  |  |  |  | $7.99 | 4 | 0.30 |  | $10.55 | Amazon | Amazon | $10.55 | Por comprar | $0.00 | $10.55 | $10.55 |  | https://www.amazon.com/dp/B0GYP4NNBR | Los NEMA suelen traer cable corto; J2 y J3 necesitan ≈1 m por los ejes huecos. | $7.99 | $10.55
ELE-09 | Motores y electrónica | Cables Dupont (80 pzs, 15 cm) |  | Pruebas y conexiones del cabezal | MathBot | 1 | Recomendado | Steren (ARD-310) | $3.99 | 1 | Verificado en línea 06-oct-2026 |  |  |  | $3.99 |  | Local | Local | $3.99 | Ya lo tenemos | $0.00 | $0.00 | $0.00 |  |  | Tienen jumpers de sobra. | $0.00 | $3.99
ELE-10 | Motores y electrónica | Jack DC hembra + bornera de potencia | 5.5 × 2.1 mm | Entrada de 12 V a la CNC Shield | HTM | 1 | Obligatorio | Casa Rivas | $1.50 | 1 | Estimado |  |  |  | $1.12 |  | Local | Local | $1.12 | Por comprar | $0.00 | $1.12 | $1.12 |  |  |  | $0.00 | $1.12
CAB-01 | Cabezal de disco | Electroimán 12 V P20/15 | Ø20 × 15 mm, 2.5 kgf, ≈0.25 A | Recoger las piezas metálicas | MathBot | 1 | Obligatorio | No se encontró en el país |  |  |  | $6.59 | 1 | 0.15 |  | $8.43 | Amazon | Amazon | $8.43 | Por comprar | $0.00 | $8.43 | $8.43 |  | https://www.amazon.com/dp/B078KBJNFC |  | $6.59 | $8.43
CAB-02 | Cabezal de disco | Sensor inductivo LJ12A3-4-Z/BX | M12, NPN NA, 6–36 V, detecta a 4 mm | Detectar metal | MathBot | 1 | Obligatorio | Prestelectro / Intek (industrial) | $35.00 | 1 | Estimado (USD 25–60) | $9.99 | 3 | 0.35 | $35.00 | $13.13 | Amazon | Amazon | $13.13 | Por comprar | $0.00 | $13.13 | $13.13 |  | https://www.amazon.com/s?k=LJ12A3-4-Z%2FBX | Paquete de 3: quedan 2 de repuesto. Uno individual (DEVMO, B07TMKTZ9L) cuesta USD 12.99. | $9.99 | $13.13
CAB-03 | Cabezal de disco | Micro servo SG90 / MG90S |  | Levantar el plumón 18 mm | MathBot | 1 | Obligatorio | Casa Rivas | $4.00 | 1 | Estimado (hay en el país) | $8.88 | 2 | 0.15 | $3.00 | $11.21 | Local | Local | $3.00 | Por comprar | $0.00 | $3.00 | $3.00 |  | https://www.amazon.com/s?k=MG90S+metal+gear+2+pack |  | $0.00 | $3.00
CAB-04 | Cabezal de disco | Plumón Sharpie punta fina | Negro | Trazar la curva paramétrica | MathBot | 2 | Obligatorio | Librería o supermercado | $1.50 | 1 | Estimado | $1.97 | 2 | 0.05 | $3.00 | $2.53 | Amazon | Local | $3.00 | Por comprar | $0.00 | $3.00 | $3.00 |  | https://www.amazon.com/dp/B00144862U |  | $0.00 | $2.53
CAB-05 | Cabezal de disco | Resorte de compresión | Ø10–12 × 20 mm | Porta-plumón con amortiguación | MathBot | 1 | Obligatorio | Vidrí / Freund | $0.50 | 1 | Estimado | $6.58 | 1 | 0.50 | $0.50 | $9.41 | Local | Local | $0.50 | Por comprar | $0.00 | $0.50 | $0.50 |  | https://www.amazon.com/dp/B0F47T44GH | Amazon solo vende kits de 390 resortes. | $0.00 | $0.50
CAB-06 | Cabezal de disco | Separador M4 × 25 mm + tuercas | Varilla roscada o espaciador | Colgar el electroimán del disco | MathBot | 1 | Obligatorio | Vidrí | $0.60 | 1 | Estimado |  |  |  | $0.60 |  | Local | Local | $0.60 | Por comprar | $0.00 | $0.60 | $0.60 |  |  | Las piezas impresas del cabezal están en la hoja Impresión 3D. | $0.00 | $0.60
MB-01 | Electrónica MathBot | MOSFET IRLZ44N + resistencias 220 Ω / 10 kΩ | Nivel lógico | Encender el electroimán desde A1 | MathBot | 1 | Obligatorio | Casa Rivas | $1.50 | 1 | Estimado (hay en el país) | $9.49 | 1 | 0.10 | $1.12 | $11.81 | Local | Local | $1.12 | Por comprar | $0.00 | $1.12 | $1.12 |  | https://www.amazon.com/dp/B088NH81S9 | Alternativa ya armada: módulo D4184 (Amazon). | $0.00 | $1.12
MB-02 | Electrónica MathBot | Diodo 1N5819 o 1N4007 |  | Flyback del electroimán | MathBot | 2 | Obligatorio | Casa Rivas | $0.15 | 1 | Estimado | $7.99 | 100 | 0.10 | $0.22 | $9.99 | Local | Local | $0.22 | Por comprar | $0.00 | $0.22 | $0.22 |  | https://www.amazon.com/dp/B079KG1TN2 |  | $0.00 | $0.22
MB-03 | Electrónica MathBot | Optoacoplador PC817 + resistencias |  | Llevar la señal de 12 V del sensor a A2 | MathBot | 1 | Obligatorio | Casa Rivas | $0.60 | 1 | Estimado | $6.99 | 1 | 0.10 | $0.45 | $8.78 | Local | Local | $0.45 | Por comprar | $0.00 | $0.45 | $0.45 |  | https://www.amazon.com/dp/B0B5383L69 | Amazon: módulo armado NOYITO. | $0.00 | $0.45
MB-04 | Electrónica MathBot | Convertidor buck LM2596 | 12 → 6 V, 3 A | Alimentar el servo del cabezal | MathBot | 1 | Obligatorio | Casa Rivas / ArduStore SV | $4.00 | 1 | Estimado | $7.99 | 5 | 0.20 | $3.00 | $10.27 | Local | Local | $3.00 | Por comprar | $0.00 | $3.00 | $3.00 |  | https://www.amazon.com/dp/B0DBVYP91F |  | $0.00 | $3.00
MB-05 | Electrónica MathBot | Placa perforada 5 × 7 cm + borneras + headers |  | Montar la interfaz sobre la base | MathBot | 1 | Obligatorio | Casa Rivas | $2.50 | 1 | Estimado |  |  |  | $1.88 |  | Local | Local | $1.88 | Por comprar | $0.00 | $1.88 | $1.88 |  |  |  | $0.00 | $1.88
MB-06 | Electrónica MathBot | Cable multiconductor 6–8 hilos, AWG 24 | Flexible, por metro | Del cabezal a la base por los ejes huecos de J2 y J3 | MathBot | 2 | Obligatorio | Vidrí / Casa Rivas (cable de alarma) | $0.80 | 1 | Estimado |  |  |  | $1.20 |  | Local | Local | $1.20 | Por comprar | $0.00 | $1.20 | $1.20 |  |  |  | $0.00 | $1.20
TOR-01 | Tornillería | Surtido de tornillos Allen M3/M4/M5 + tuercas |  | Motores, abrazaderas, brazos y cabezal | HTM | 1 | Obligatorio | Vidrí / Freund (por pieza) | $15.00 | 1 | Estimado | $22.99 | 1 | 2.50 | $15.00 | $34.99 | Local | Local | $15.00 | Por comprar | $0.00 | $15.00 | $15.00 |  | https://www.amazon.com/dp/B0FG2964F5 | El artículo trae la lista de pernos en una imagen; el surtido de Amazon cubre todo pero pesa 2.5 lb. | $0.00 | $15.00
TOR-02 | Tornillería | Perno M4 × 55 + tuerca de seguridad |  | Unir la polea de J1 con el acople J1 | HTM | 4 | Obligatorio | Vidrí | $0.30 | 1 | Estimado |  |  |  | $1.20 |  | Local | Local | $1.20 | Por comprar | $0.00 | $1.20 | $1.20 |  |  |  | $0.00 | $1.20
TOR-03 | Tornillería | Perno M8 × 45 + arandela + tuerca de seguridad |  | Eje de las poleas intermedias | HTM | 2 | Obligatorio | Vidrí | $0.75 | 1 | Estimado |  |  |  | $1.50 |  | Local | Local | $1.50 | Por comprar | $0.00 | $1.50 | $1.50 |  |  |  | $0.00 | $1.50
TOR-04 | Tornillería | Perno M5 × 35 + tuercas |  | Tensores de correa | HTM | 4 | Recomendado | Vidrí | $0.25 | 1 | Estimado |  |  |  | $1.00 |  | Local | Local | $1.00 | Por comprar | $0.00 | $1.00 | $1.00 |  |  |  | $0.00 | $1.00
TOR-05 | Tornillería | Tornillo M4 + tuerca |  | Fijar la base a la madera (12 agujeros) | HTM | 12 | Recomendado | Vidrí | $0.12 | 1 | Estimado |  |  |  | $1.44 |  | Local | Local | $1.44 | Por comprar | $0.00 | $1.44 | $1.44 |  |  |  | $0.00 | $1.44
VAR-01 | Impresión y varios | Filamento PLA+ 1.75 mm | Rollo de 1 kg | Todas las piezas impresas (ver hoja Impresión 3D) | HTM | 2 | Obligatorio | El Changarro (PLA 1 kg) | $27.99 | 1 | Indexado en buscador (oferta) | $11.19 | 1 | 2.90 | $55.98 | $43.58 | Amazon | Amazon | $43.58 | Ya lo tenemos | $0.00 | $0.00 | $0.00 |  | https://www.amazon.com/dp/B07XG3RM58 | Impresión gratuita: todas las piezas impresas quedan sin costo. Avalon Tech publicaba USD 30, pero cerró su tienda en línea en jul-2026: preguntar por WhatsApp. Si la universidad imprime, poner 'Ya lo tenemos'. | $0.00 | $43.58
VAR-02 | Impresión y varios | Cinchos sujetacables | Paquete corto, negro | Ordenar los cables | HTM | 1 | Recomendado | Steren (TY24NE) | $2.49 | 1 | Verificado en línea 06-oct-2026 |  |  |  | $2.49 |  | Local | Local | $2.49 | Por comprar | $0.00 | $2.49 | $2.49 |  |  |  | $0.00 | $2.49
VAR-03 | Impresión y varios | Funda trenzada para cables 1/4" |  | Mazo de cables de la columna | HTM | 1 | Opcional |  |  |  |  | $9.99 | 1 | 0.30 |  | $12.98 | Amazon | Amazon | $12.98 | No comprar | $0.00 | $0.00 | $0.00 |  | https://www.amazon.com/dp/B07RZXSJBM |  | $0.00 | $12.98
VAR-04 | Impresión y varios | Tubo termorretráctil (surtido) |  | Aislar empalmes | MathBot | 1 | Recomendado | Casa Rivas | $2.00 | 1 | Estimado | $6.64 | 1 | 0.30 | $1.50 | $8.91 | Local | Local | $1.50 | Por comprar | $0.00 | $1.50 | $1.50 |  | https://www.amazon.com/dp/B01MFA3OFA |  | $0.00 | $1.50
VAR-05 | Impresión y varios | Gestión de casillero (por envío) |  | Cargo fijo por paquete consolidado | MathBot | 1 | Obligatorio | Casillero en Miami (p. ej. QuickBox) | $3.50 | 1 | Estimado |  |  |  | $3.50 |  | Local | Local | $3.50 | Por comprar | $0.00 | $3.50 | $3.50 |  |  | El flete por libra ya va dentro del 'Total Amazon puesto en SV'. Esta línea es solo la gestión; ajusten el número de envíos en Supuestos. | $0.00 | $3.50
 |  | Totales |  |  |  |  |  |  |  |  |  |  |  |  | $368.44 | $509.57 |  |  | $411.77 |  | $0.00 | $238.73 | $238.73 |  |  |  | $128.92 | $381.42
 |  | Nota: 'Total local' y 'Total Amazon' suman todas las filas aunque no se compren; el costo real del proyecto está en 'Proyección'.
 |  | Naranja en 'Fuente elegida' = hay una opción más barata. Gris = fila que no se compra (no suma).

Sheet: Registro de gastos
Registro de gastos
Una fila por pago. El ID enlaza con la lista de materiales: el 'Gastado real' de cada ítem y del resumen se calcula de aquí. Al terminar una compra, cambien el Estado del ítem a 'Comprado'.
Ejemplo de cómo llenar una fila (no se suma):
Fecha | ID ítem | Componente | Tienda | Cantidad | Monto pagado (USD) | Pagó | Método de pago | Comprobante | Notas
06/10/2026 | ELE-01 | Motor paso a paso NEMA 17, 40 mm | Electrónica 2001 | 3 | $36.00 | Integrante 1 | Tarjeta | Factura 1234 | Pedido para retirar
Pagos del proyecto
Fecha | ID ítem | Componente | Tienda | Cantidad | Monto pagado (USD) | Pagó | Método de pago | Comprobante | Notas | Total pagado
 |  |  |  |  |  |  |  |  |  | $0.00

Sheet: Impresión 3D
Gramos estimados con el volumen real de cada STL: paredes y techos de 1.1 mm sólidos + 25 % de relleno, PLA 1.24 g/cm³. Las poleas GT2 se imprimen (el artículo usa PLA normal). Las piezas de la pinza original no se imprimen.
Gramos estimados | 1453.5 g
Gramos con merma | 1627.92 g
Rollos de 1 kg a comprar | 2 | ← lo lee VAR-01 (filamento) en la lista de materiales
Horas de impresión | 124.2307692 h
Avance (gramos impresos) | 0.0%
Costo del filamento (USD) | $0.00
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

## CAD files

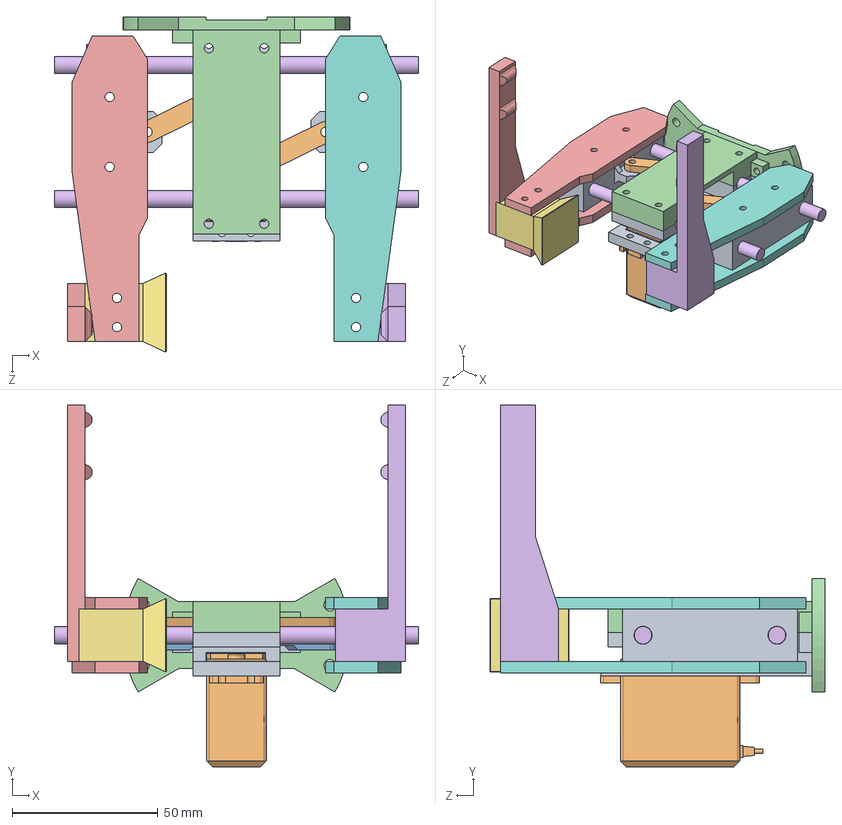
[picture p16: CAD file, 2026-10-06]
BRAZO SCARA/DISEÑO FINAL/SCARA Robot 3D Model - Solidworks Files/Gripper Mechanism.SLDASM
125.0 x 124.2 x 115.1 mm
Servo Holder
Servo Motor MG996R 3D Model
Servo MG996R Horn
Gripper Cover
Gripper Hand Left x 2
Gripper rail 6mm x 2
Gripper Hand Right x 2
Gripper Mechanism Slider x 2
Gripper link 1 x 2
Gripper link 2 x 2
Gripper to J3 connector
Wide gripper end
Wide gripper end - Left side

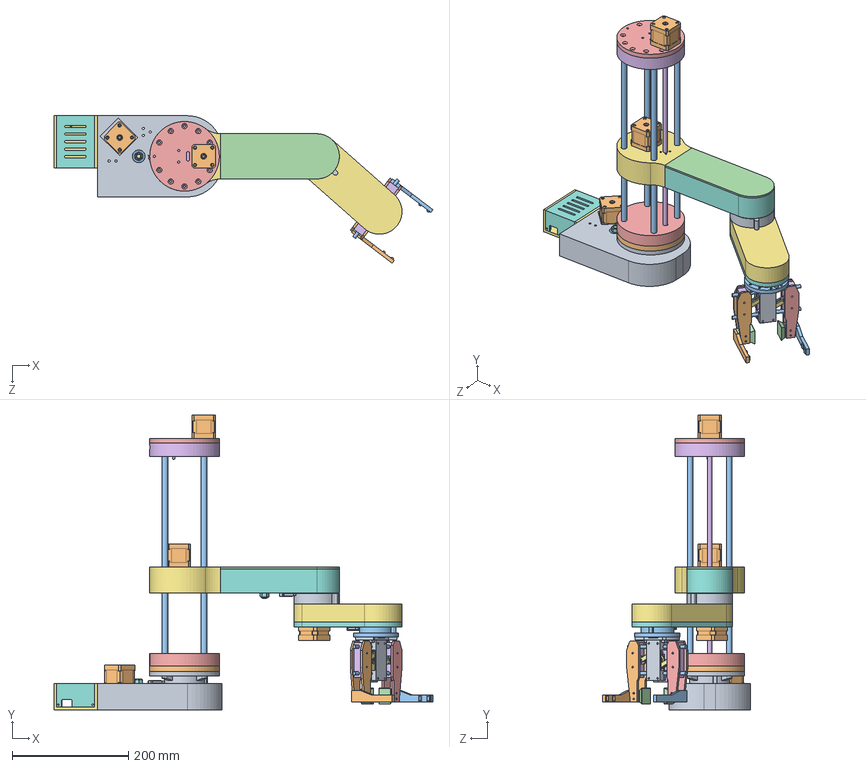
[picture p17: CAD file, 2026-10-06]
BRAZO SCARA/DISEÑO FINAL/SCARA Robot 3D Model - Solidworks Files/SCARA Robot.SLDASM
653.4 x 508.0 x 254.4 mm
Base
Stepper NEMA 17 - 20mm shaft x 3
Ball Bearing 608 - 8x22x7mm x 5
Thrust Bearing - 40x60x13 x 2
GT2 Pulley - 110 teeth - J1
GT2 Pulley - 22 - 80 teeth
GT2 Pulley - Parametric x 3
M8 Washer x 2
J1 coupler
Z-axis Bottom Plate
Smooth Rod D10mm L400mm x 4
Smooth Rod Clamp x 8
Z-axis Top Plate
Lead Screw D8mm L380mm
Z-axis Mount Platform
Arm 1
J2 Coupler
Thrust Bearing 35x52x12mm x 4
Ball Bearing 30x42x7mm x 2
GT2 Pulley - 92 teeth - J2
GT2 Pulley - 23 - 80 teeth
Linear Bearing 10x19x29mm x 4
Arm 2
Arm 2 Cover
Micro switch x 4
NEMA 17 Stepper L24mm - 20mm shaft
J3 Coupler
GT2 Pulley - 90 teeth - J3
Lead Screw Nut 8mm
Servo Holder
Servo Motor MG996R 3D Model
Servo MG996R Horn
Gripper Cover
Gripper Hand Left x 2
Gripper rail 6mm x 2
Gripper End x 2
Gripper Hand Right x 2
Gripper Mechanism Slider x 2
Gripper link 1 x 2
Gripper link 2 x 2
Gripper to J3 connector
Arm 1 Cover
Base cover
Top cover
Arduino UNO case p1
Arduino UNO case p2
GT2 Belt 200mm
GT2 Belt 300mm 2
GT2 Belt 400mm
GT2 Belt 300mm
GT2 Belt 400mm 2
Ball Bearing 35x47x7mm
M8 45mm - Bolts x 2
M8 Lock nut x 2
M4 Lock nut x 8
M4 60mm - Bolts x 4
M4 50mm - Bolts x 4

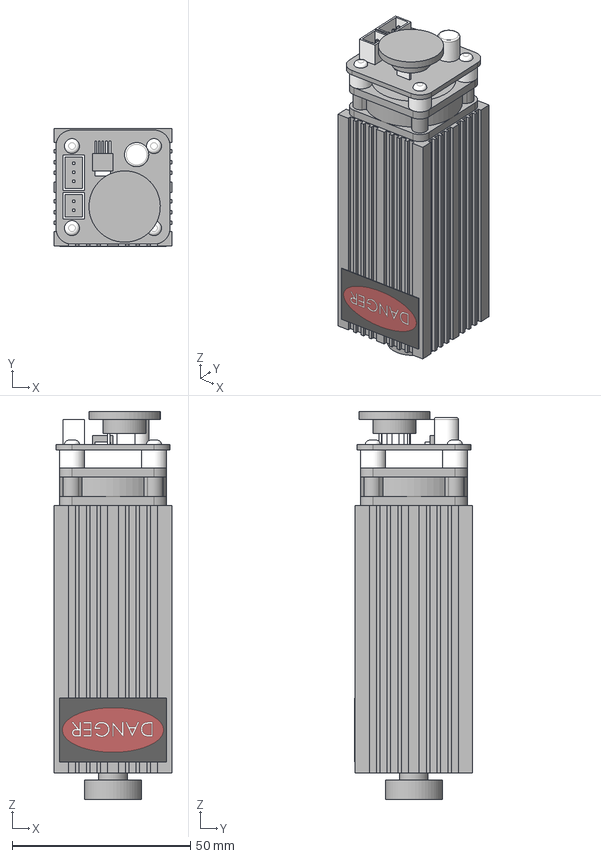
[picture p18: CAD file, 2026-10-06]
BRAZO SCARA/DISEÑO FINAL/Laser Engraving Mode - STL and editable files/Laser Module 5.5W.step
33.0 x 33.2 x 108.8 mm

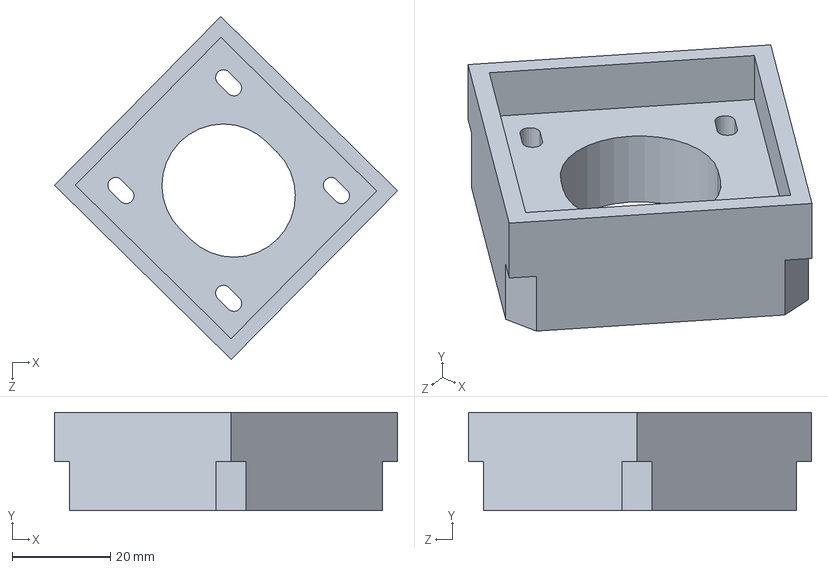
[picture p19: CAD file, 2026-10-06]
BRAZO SCARA/DISEÑO FINAL/Personalized/acople motor 3.SLDPRT
69.8 x 20.0 x 69.8 mm

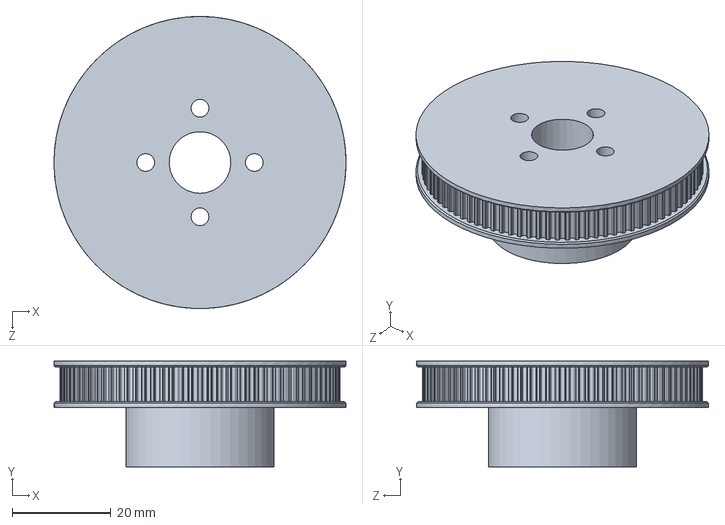
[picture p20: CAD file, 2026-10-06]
BRAZO SCARA/DISEÑO FINAL/SCARA Robot 3D Model - Solidworks Files/GT2 Pulley - 90 teeth - J3.SLDPRT
59.2 x 21.4 x 59.2 mm

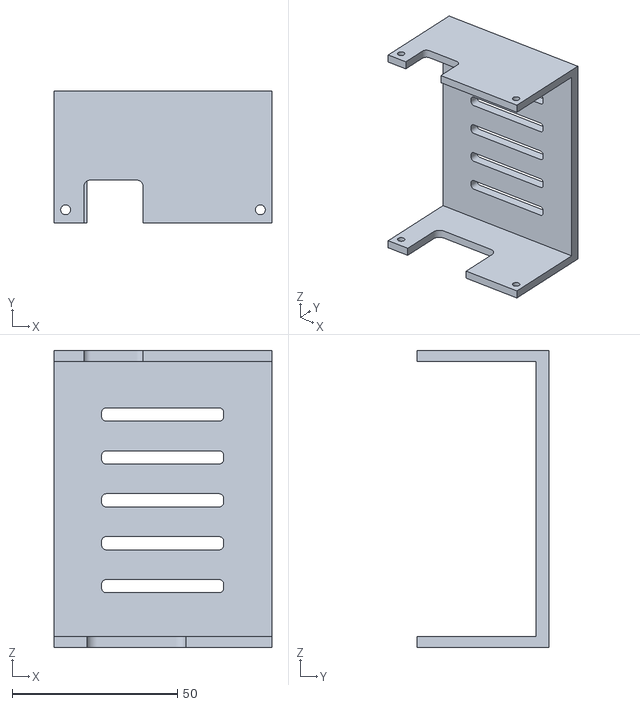
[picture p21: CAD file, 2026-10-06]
BRAZO SCARA/DISEÑO FINAL/SCARA Robot Arm - STL Files - updated/Arduino UNO case p2.STL
66.0 x 40.0 x 90.0

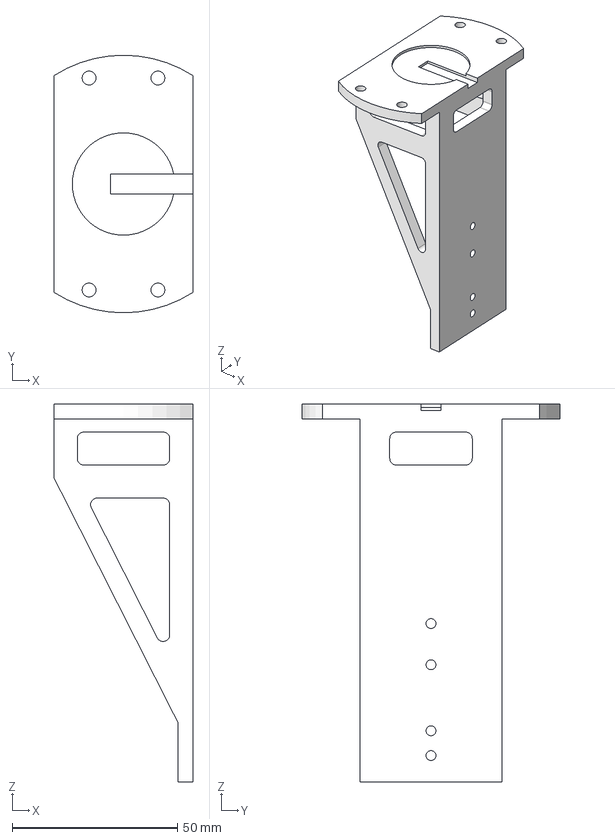
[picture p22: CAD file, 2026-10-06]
BRAZO SCARA/DISEÑO FINAL/Laser Engraving Mode - STL and editable files/Laser module holder.step
42.0 x 78.0 x 114.5 mm

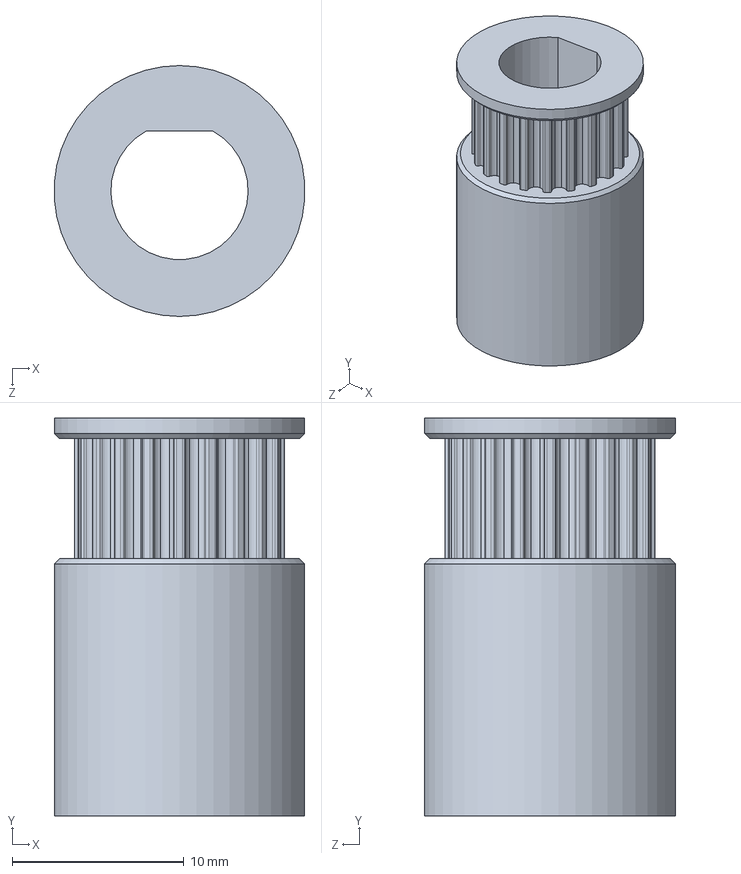
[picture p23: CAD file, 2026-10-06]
BRAZO SCARA/DISEÑO FINAL/Personalized/GT2 Pulley - Parametric Nema 23.SLDPRT
14.6 x 23.2 x 14.6 mm

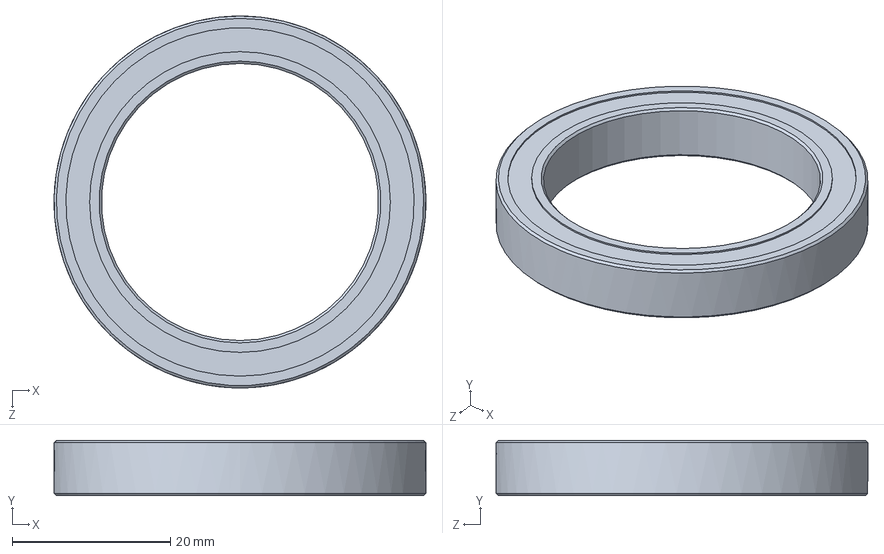
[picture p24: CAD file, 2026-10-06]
BRAZO SCARA/DISEÑO FINAL/SCARA Robot 3D Model - Solidworks Files/Ball Bearing 35x47x7mm.SLDPRT
47.0 x 7.00 x 47.0 mm

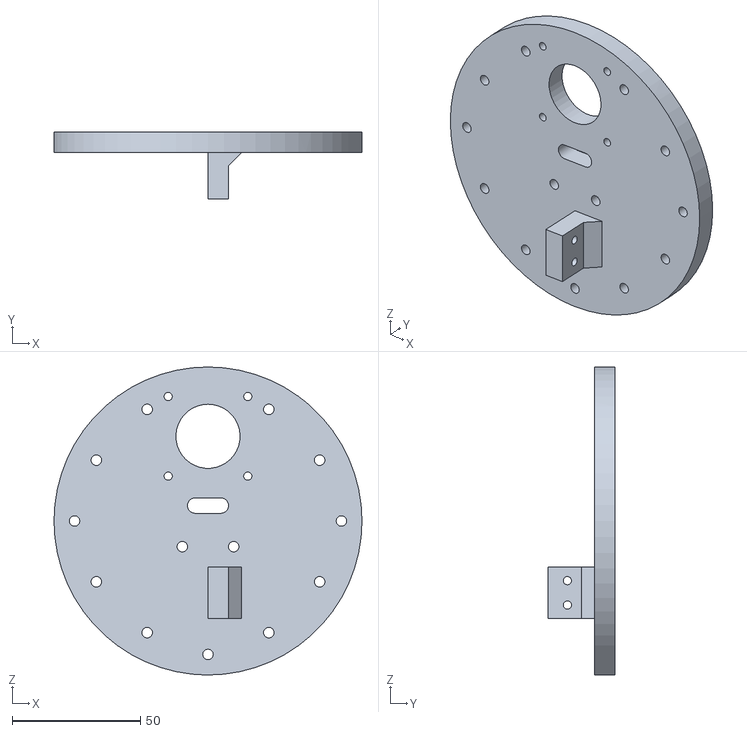
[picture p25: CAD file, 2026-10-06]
BRAZO SCARA/DISEÑO FINAL/SCARA Robot Arm - STL Files - updated/Z-axis Top Plate.STL
120.0 x 26.0 x 120.0

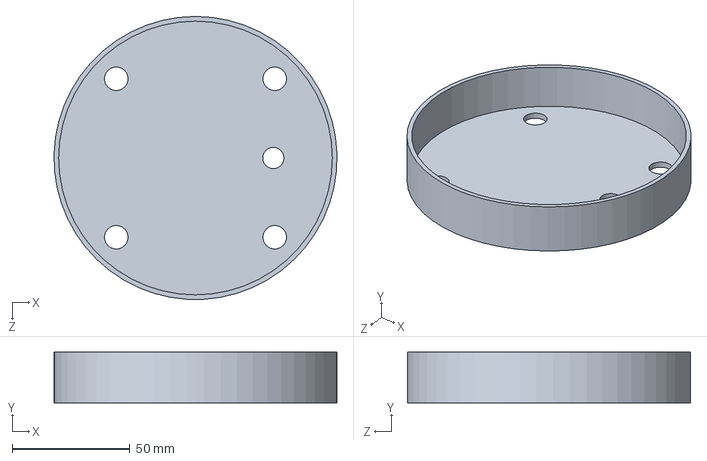
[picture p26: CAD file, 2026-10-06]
BRAZO SCARA/DISEÑO FINAL/SCARA Robot 3D Model - Solidworks Files/Base cover.SLDPRT
119.9 x 21.5 x 120.0 mm

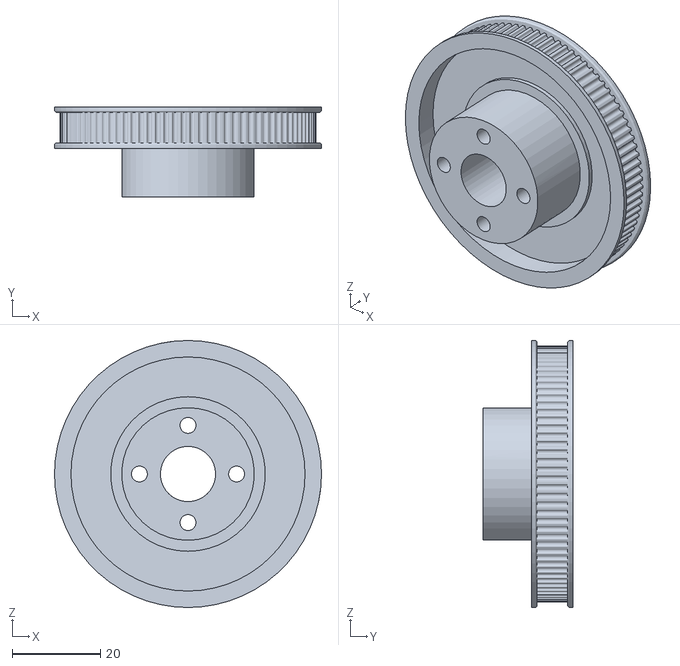
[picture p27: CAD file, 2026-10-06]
BRAZO SCARA/DISEÑO FINAL/SCARA Robot Arm - STL Files - updated/GT2 Pulley - 92 teeth - J2.STL
60.5 x 20.4 x 60.5

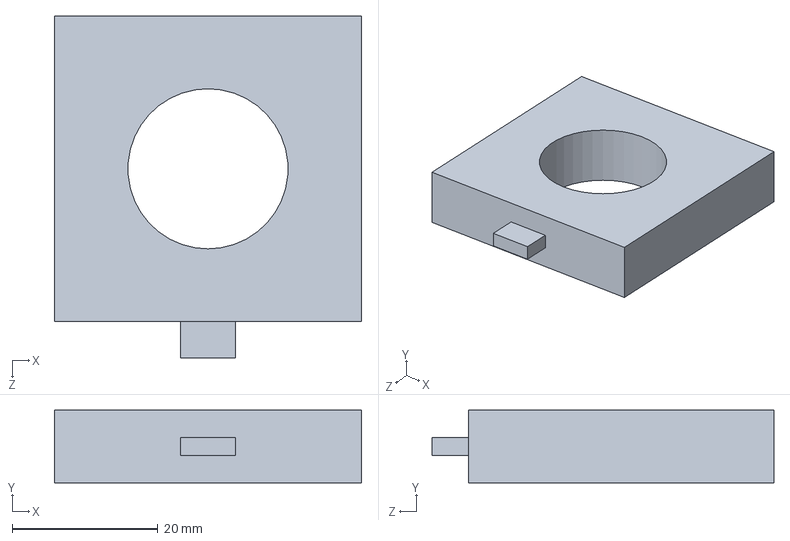
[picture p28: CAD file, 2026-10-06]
BRAZO SCARA/DISEÑO FINAL/Personalized/Base_motor.SLDPRT
42.2 x 10.0 x 47.0 mm

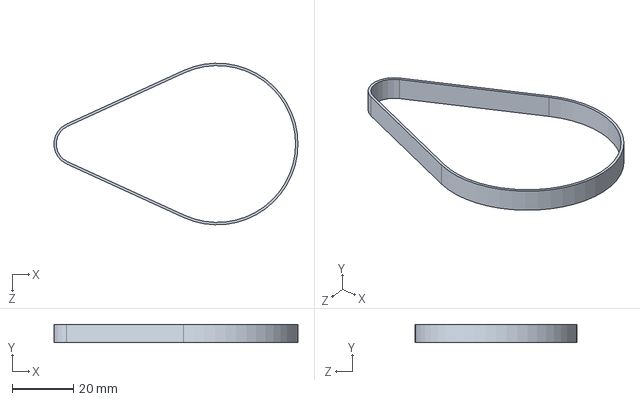
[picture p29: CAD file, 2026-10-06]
BRAZO SCARA/DISEÑO FINAL/SCARA Robot 3D Model - Solidworks Files/GT2 Belt 200mm.SLDPRT
79.4 x 6.00 x 52.6 mm

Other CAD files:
BRAZO SCARA/DISEÑO FINAL/SCARA Robot 3D Model.SLDASM
BRAZO SCARA/DISEÑO FINAL/SCARA Robot 3D Model - Solidworks Files/SCARA Robot 3D Model.SLDASM
BRAZO SCARA/DISEÑO FINAL/Personalized/GT2 Pulley - Parametric Nema 23 v2.STL
BRAZO SCARA/DISEÑO FINAL/SCARA Robot Arm - STL Files - updated/Laser module holder.STL
BRAZO SCARA/DISEÑO FINAL/Laser Engraving Mode - STL and editable files/Laser Module 5.5W.SLDPRT
BRAZO SCARA/DISEÑO FINAL/Laser Engraving Mode - STL and editable files/Laser module holder.SLDPRT
BRAZO SCARA/DISEÑO FINAL/Laser Engraving Mode - STL and editable files/Laser module holder.STL
BRAZO SCARA/DISEÑO FINAL/Personalized/GT2 Pulley - Parametric Nema 23.STL
BRAZO SCARA/DISEÑO FINAL/Personalized/acople motor 3.STL
BRAZO SCARA/DISEÑO FINAL/SCARA Robot 3D Model - Solidworks Files/Arduino UNO case p1.SLDPRT
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

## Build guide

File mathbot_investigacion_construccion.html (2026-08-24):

MATHBOT · PBL 2026-2 Física Aplicada III + Cálculo III Investigación de construcción v1 · 20 ago 2026

# Cómo construir el MATHBOT

Arquitecturas candidatas, presupuesto de error, lista de materiales y costo. Seis rutas de construcción comparadas contra los requisitos reales del PBL. No contra lo que se ve bien en un video.

## Veredicto

Construir un SCARA de sobremesa de 3 GDL más un cabezal de doble efector (θ₁ y θ₂ horizontales, eje Z vertical), con eslabones de 20 cm y la base a 22 cm del centro de la rosa. Es la única arquitectura que gana en los tres frentes a la vez: la tarea es plana y el SCARA es la máquina plana por definición; la gravedad no carga las articulaciones que dibujan; y la cinemática inversa tiene forma cerrada con dos ramas: material matemático real para Cálculo III, no un ejercicio decorativo.

La decisión crítica no es la geometría sino el actuador. Con servos hobby MG996R en accionamiento directo, el error de trazo llega a 8,7 mm por cada grado de error articular, y la zona muerta de esos servos es de 1–2°. Eso solo ya destruye el presupuesto de error. La corrección es servo de bus serie con encóder (Feetech STS3215, 0,088° por cuenta) o reducción por correa 6:1 sobre servos analógicos.

Costo estimadoUSD 265ruta recomendada, sin herramientas

Error de trazo≈ 2,0 mmRSS del presupuesto · meta < 3 mm

Precisión resultante98,5 %frente al 90 % exigido

Dificultad3 / 5media · 7–9 semanas

01

## Requisitos que filtran el diseño

El enunciado del PBL impone restricciones duras. Antes de comparar arquitecturas conviene extraerlas, porque varias de las opciones «obvias» de internet quedan eliminadas por una sola línea del documento.

# | Requisito literal | Consecuencia de diseño

R1 | «control individual y verificable de cada servomotor» | Los actuadores deben ser servos, o al menos lazos cerrados con lectura de posición. Una CNC de steppers en lazo abierto no cumple la letra del requisito.
R2 | «doble efector final: pinza mecánica y electroimán intercambiable» | El cabezal debe llevar dos herramientas y un mecanismo de cambio. Suma masa y momento de inercia en la punta: pesa sobre la elección de estructura.
R3 | «sensor capaz de distinguir el tipo de material de dos objetos desconocidos» | No basta detectar presencia: hay que clasificar. Un solo sensor de proximidad no discrimina; se necesita un par inductivo + capacitivo (§07).
R4 | «objeto metálico de aproximadamente 70 g» | Carga útil mínima 70 g más el peso del cabezal. Define el torque de los servos y la fuerza del electroimán.
R5 | «simulación 3D en Simulink … con la geometría y dimensiones del prototipo real» | El CAD debe existir antes de cortar material y ser exportable a Simscape Multibody. Diseñar en CAD deja de ser opcional.
R6 | «relacionar la trayectoria matemática con el movimiento de sus articulaciones» | Debe haber cinemática inversa no trivial. Una máquina cartesiana tiene θ = p y vuelve vacío el entregable de Cálculo III.
R7 | «precisión mínima del 90 %» | Umbral cuantitativo. Obliga a un presupuesto de error explícito (§02) y a definir el criterio antes de medir.
R8 | «principios de Electricidad y Magnetismo … sensor capacitivo y electroimán» | El sensor y el electroimán deben poder explicarse con física, no comprarse como caja negra. Favorece un sensor capacitivo construido o al menos caracterizado por el equipo.

Requisitos extraídos de MATHBOT_-_Semestre_2_2026.pdf, páginas 1–3.

### La geometría de la tarea

La trayectoria asignada es una rosa de tres pétalos con A = 10,29 cm y k = 1,355. Sus dimensiones reales, calculadas sobre la parametrización del repositorio, determinan el tamaño de la máquina:

x(t) = −A·cos(3t)·cos(t) y(t) = −A·k·cos(3t)·sin(t) t ∈ [0, π]
Extensión en x: −10,29 … +5,79 cm (ancho 16,1 cm)
Extensión en y: −12,27 … +12,27 cm (alto 24,5 cm)
Radio máximo: 13,16 cm → el trazo cabe en un disco de 26,3 cm de diámetro
Puntas de pétalo: (−10,29, 0) · (+5,15, +12,07) · (+5,15, −12,07)

La curva pasa por el origen tres veces (donde cos 3t = 0), es plana, y su dimensión mayor es de 24,5 cm. Todo el trabajo ocurre en un plano horizontal de aproximadamente 17 × 25 cm: esa es la observación que decide la arquitectura.

02

## Presupuesto de error: el número que manda

El 90 % de precisión no significa nada hasta que se define respecto de qué. Hay tres criterios defendibles y dan resultados muy distintos:

Criterio | Tolerancia | Comentario
Error respecto del radio máximo e ≤ 10 % · Rmáx = 10 % · 131,6 mm | 13,2 mm | Recomendado. Estable, medible y fácil de defender: la escala característica de la figura es su radio máximo.
Error respecto del radio local e ≤ 10 % · r(t) | → 0 mm | Inviable La rosa pasa por el origen: r(t) → 0 y la tolerancia se anula. No usar.
Error respecto de la longitud de arco e ≤ 10 % · L/3 por pétalo | ≈ 9 mm | Válido pero menos intuitivo de explicar en la defensa oral.

Criterios candidatos para cuantificar el 90 %. Conviene fijarlo antes del Avance 1 y dejarlo escrito.

Recomendación

Adoptar eRMS ≤ 13,2 mm como criterio oficial de aprobación, y emáx < 3 mm como meta interna de ingeniería. Diseñar contra el umbral exacto no deja margen para lo que sí falla el día de la demostración: la calibración del origen y el juego mecánico tras semanas de uso.

### Reparto del error

Los errores independientes se suman en cuadratura (raíz de la suma de cuadrados, RSS), no linealmente. Este es el reparto para el diseño recomendado:

Discretización 15 pt/pétalo0,56 mm

Resolución del actuador0,77 mm

Backlash de reducción0,80 mm

Flexión de eslabones0,80 mm

Calibración del origen1,20 mm

Total RSS esperado1,99 mm

Tolerancia disponible13,2 mm

Margen de 6,6× sobre el criterio de aprobación. Esa holgura es lo que permite perder puntos en el montaje real sin reprobar el entregable.

### La amplificación de Jacobiano: el hallazgo que decide todo

En un brazo articulado, el error angular de cada junta se amplifica hasta la punta según la matriz jacobiana. Para la configuración recomendada (L₁ = L₂ = 20 cm, base a 22 cm) se evaluó J sobre los 1 201 puntos de la trayectoria:

δp = J(θ) · δθ

Peor caso sobre la trayectoria, con |δθᵢ| = 1° en ambas juntas:
‖δp‖máx = 8,70 mm por grado
Número de condición máximo de J: cond(J) = 3,50 → configuración bien condicionada

Actuador | Error angular efectivo | Error de trazo | Veredicto
MG996R directo (zona muerta 2°) | 2,0° | 17,4 mm | Reprueba
MG996R directo (mejor caso 1°) | 1,0° | 8,7 mm | Al filo
MG996R + reducción 4:1 | 0,50° | 4,4 mm | Aceptable
MG996R + reducción 6:1 | 0,25° | 2,2 mm | Cumple
Feetech STS3215 (encóder 12 bits) | 0,088° | 0,77 mm | Cumple con margen
NEMA 17 + correa 20:1, 1/16 µpaso | 0,006° | 0,05 mm | Sobra pero incumple R1

Error de trazo calculado como ‖J‖·δθ en el peor punto de la rosa. Los cálculos están en docs/analisis/.

Conclusión no obvia

Nadie reprueba este proyecto por elegir mal la geometría del brazo. Se reprueba por elegir servos de 4 dólares en accionamiento directo y descubrirlo en la semana 15. La reducción mecánica en θ₁ y θ₂, o un servo con encóder, no es una mejora opcional: es el requisito habilitante de todo el presupuesto de error.

03

## Seis arquitecturas comparadas

Cada ficha lleva la referencia del proyecto público más cercano, dificultad de 1 a 5 y costo estimado del subsistema mecánico y de actuación (sin electrónica común ni efectores).

### A · Brazo antropomórfico de 5–6 GDL con servos

Ref: EEZYbotARM Mk2 (Instructables) · DIY Arduino Robot Arm (HowToMechatronics) · kits Fabri Creator

Dificultad mecánica ●●●●● Dificultad matemática ●●●●● Costo USD 70–170 Error esperado 8–20 mm

Es la imagen mental por defecto de «brazo robótico»: base giratoria, hombro, codo, muñeca y pinza, todo impreso en 3D y movido por MG996R y SG90. Es la opción más documentada del planeta y la que más se parece a un robot industrial en las fotos.

##### A favor

- Documentación abundante: STL, código y video paso a paso, con comunidad grande.
- Cumple R2 de forma natural: la muñeca es el lugar obvio para un cabezal intercambiable.
- Cinemática inversa de 5 GDL: material de sobra para Cálculo III.
- Kits comerciales listos desde USD 69, con envío internacional.

##### En contra

- La gravedad carga hombro y codo durante todo el trazo. El error cambia con la postura y es difícil de calibrar.
- Cadena serie larga: el juego de cada junta se acumula hacia la punta.
- Con MG996R directos, error de 8 a 20 mm. Justo en el límite o por encima.
- Mantener el efector a altura constante sobre el papel requiere coordinar 3 juntas; en un SCARA es una sola.
- La flexión del PLA bajo carga lateral es el error dominante y no se elimina calibrando.

Veredicto: viable pero es la ruta que más pelea contra el requisito de precisión. Elegirla solo si el equipo prioriza la apariencia industrial y acepta invertir en reducción mecánica en hombro y codo, con lo que el costo se acerca al del SCARA sin igualar su rigidez en el plano.

### B · SCARA de sobremesa, 3 GDL + cabezal Recomendado

Ref: SCARA Robot · HowToMechatronics (4 GDL, NEMA 17, CNC Shield, GT2)

Dificultad mecánica ●●●●● Dificultad matemática ●●●●● Costo USD 130–220 Error esperado 1–3 mm

Dos juntas rotacionales de eje vertical mueven el efector en el plano XY; un tercer eje lo sube y lo baja. El nombre lo dice todo: Selective Compliance Assembly Robot Arm, rígido en la vertical y complaciente en el plano. Es la arquitectura que la industria usa para pick-and-place plano, que es exactamente esta tarea.

##### A favor

- La gravedad no genera torque en θ₁ ni θ₂. Los servos que dibujan solo vencen inercia y fricción: torques mucho menores y error independiente de la postura.
- Rigidez vertical alta: el efector no se hunde ni rebota sobre el papel.
- Cinemática inversa en forma cerrada con dos ramas (codo arriba / codo abajo): decisión matemática real y defendible en el informe.
- El análisis de singularidades y el número de condición del jacobiano alimentan directamente el entregable de optimización del Avance 2.
- Menos juntas que mover: menos servos, menos cableado, menos fuentes de error.
- Se puede montar sobre una base plana de MDF cortada en el SPARK.

##### En contra

- Requiere rodamientos axiales decentes en las dos juntas: sin ellos el eslabón cabecea y se pierde la ventaja.
- Menos «espectacular» a la vista que un brazo antropomórfico.
- El eje Z añade un mecanismo (husillo o cremallera) que hay que diseñar.
- Los ejemplos públicos usan steppers; hay que adaptar el diseño a servos para cumplir R1.

Veredicto: mejor relación entre precisión, esfuerzo y riqueza matemática. Se detalla en §05.

### C · Máquina cartesiana / CNC casera tipo pórtico

Ref: OpenBuilds ACRO System · V-Slot + GRBL + Universal G-code Sender

Dificultad mecánica ●●●●● Dificultad matemática ●●●●● Costo USD 250–700 Error esperado 0,1–0,5 mm

Un pórtico XY con perfil de aluminio V-Slot, ruedas Delrin y correas GT2, controlado por GRBL. Es, con diferencia, la máquina más precisa de esta lista y la más fácil de hacer funcionar: el ecosistema OpenBuilds está resuelto de fábrica.

##### A favor

- Precisión de décimas de milímetro sin esfuerzo de calibración.
- GRBL y Universal G-code Sender funcionan el primer día.
- Perfil de aluminio: rigidez estructural fuera del alcance del PLA.

##### En contra

- Vacía el entregable de Cálculo III. La cinemática inversa de una cartesiana es la identidad: θ = p. No hay nada que modelar, y R6 pide explícitamente relacionar la trayectoria con el movimiento articular.
- Usa steppers en lazo abierto: choca con R1, que exige servomotores con control verificable.
- No es un brazo robótico. El enunciado dice «brazo» ocho veces.
- El más caro: un kit ACRO mecánico ronda los 1 700 EUR; una versión casera equivalente, entre 250 y 700 USD.
- Montar el doble efector y el eje Z sobre un pórtico es posible pero pesado.

Veredicto: Descartada Paradoja útil para el informe: la arquitectura con mejor precisión es la que peor califica. Vale la pena documentar por qué se descartó. Esa justificación es exactamente la «bitácora de alternativas» que pide el entregable I de Física III.

### D · Brazo polar de dos eslabones (plotter θ–r)

Ref: plotters polares y de doble brazo tipo AxiDraw / drawbot

Dificultad mecánica ●●●●● Dificultad matemática ●●●●● Costo USD 80–140 Error esperado 2–5 mm

Es un SCARA sin eje Z: dos eslabones planos y un pequeño servo que levanta el lápiz. La versión mínima viable de la opción B.

##### A favor

- La más barata y rápida de construir con buena precisión de trazo.
- Misma cinemática inversa que el SCARA: sirve igual para Cálculo III.
- Excelente como prototipo de la semana 3 para validar el Avance 1.

##### En contra

- Sin eje Z real no puede levantar ni transportar el objeto de 70 g: incumple R4.
- No hay dónde montar el doble efector: incumple R2.
- El servo de subir y bajar el lápiz no sustituye una carrera vertical de trabajo.

Veredicto: no sirve como entrega final, pero sí como paso intermedio deliberado. Construirlo primero valida la ecuación paramétrica, la cinemática inversa y el firmware con un costo bajo, y luego el eje Z y el cabezal lo convierten en la opción B. Esta ruta escalonada es la que mejor se ajusta al «trabajo iterativo documentado» que evalúan ambos cursos.

### E · Robot delta / paralelo

Ref: mini delta impresos en 3D, arquitectura tipo ABB FlexPicker

Dificultad mecánica ●●●●● Dificultad matemática ●●●●● Costo USD 120–200 Error esperado 1–4 mm

Tres brazos paralelos mueven una plataforma. Rápido, ligero en la punta y con la cinemática inversa más elegante de toda la lista.

##### A favor

- Actuadores fijos a la base: masa móvil mínima, muy poca flexión.
- La cinemática inversa (intersección de tres esferas) es matemáticamente rica.

##### En contra

- Doce juntas esféricas que fabricar y que introducen juego: la parte más difícil de imprimir bien.
- Volumen de trabajo cónico y estrecho: 24,5 cm de trazo obliga a un delta grande.
- Cinemática directa sin forma cerrada limpia; complica la validación en Simulink.
- Muy poca tolerancia a errores de fabricación: el margen de aprendizaje es escaso.

Veredicto: Descartada El riesgo de fabricación no se compensa con ninguna ventaja para esta tarea. Es el proyecto que se ve brillante en la semana 4 y sigue sin funcionar en la semana 16.

### F · Comprar un kit comercial y modificarlo

Ref: Fabri Creator (Kit 4.0 USD 69 · 4.1 USD 79 · 5.0 USD 169) · SO-101 / LeRobot (≈ USD 150)

Dificultad mecánica ●●●●● Dificultad matemática ●●●●● Costo USD 69–190 Error esperado 3–15 mm

Fabri Creator vende kits de brazo en español con envío internacional gratuito y soporte por WhatsApp. El SO-101 del ecosistema LeRobot es de código abierto, usa seis servos de bus serie Feetech STS3215 con encóder magnético de 360° y cuesta alrededor de USD 150 en su versión DIY.

##### A favor

- Elimina semanas de fabricación y depuración mecánica.
- El SO-101 trae exactamente los servos que resuelven el problema de precisión (§06) y publica STL, código y BOM.
- Libera tiempo para lo que sí se evalúa: el modelo, la simulación y el control.
- Un kit de bajo costo es una fuente legítima de piezas: comprar el kit de electrónica del SO-101 y diseñar la estructura propia.

##### En contra

- El entregable I de Física III evalúa el diseño físico y la bitácora de alternativas. Comprar el brazo entero deja ese 5 % sin evidencia propia.
- Los kits baratos (USD 69) son brazos antropomórficos con MG996R: heredan todos los problemas de la opción A.
- R5 exige que el modelo de Simulink refleje «el brazo real construido por el equipo».
- Riesgo de tiempos de envío de 8 a 15 días más aduana.

Veredicto: Ruta híbrida No comprar el brazo completo. Sí comprar los servos de bus serie y su placa controladora del ecosistema SO-101, y construir la estructura SCARA propia alrededor. Se obtiene la precisión de un kit profesional conservando la autoría del diseño que exige Física III.

04

## Matriz de decisión

Arquitectura | Error | Costo | Dif. | R1 servos | R2 doble efector | R6 cinemática | Riesgo de calendario | Total
A · Antropomórfico 5–6 GDL | 8–20 mm | 70–170 | 2/5 | Sí | Sí | Rica | Bajo | 3,2 / 5
B · SCARA 3 GDL + cabezal | 1–3 mm | 130–220 | 3/5 | Sí | Sí | Rica | Medio | 4,5 / 5
C · Cartesiana / CNC | 0,1–0,5 mm | 250–700 | 2/5 | No | Difícil | Trivial | Bajo | 2,1 / 5
D · Polar 2 eslabones | 2–5 mm | 80–140 | 2/5 | Sí | No | Rica | Bajo | 3,0 / 5 como prototipo: 5/5
E · Delta paralelo | 1–4 mm | 120–200 | 5/5 | Sí | Limitado | Muy rica | Alto | 2,4 / 5
F · Kit comercial modificado | 3–15 mm | 69–190 | 1/5 | Sí | Adaptar | Rica | Envío | 3,4 / 5

Costo en USD del subsistema mecánico y de actuación. «Total» pondera precisión 30 %, ajuste a los requisitos 30 %, riesgo de calendario 25 % y costo 15 %.

Ruta elegida

D → B. Construir primero el plotter polar de dos eslabones (opción D) como banco de pruebas de la semana 3 y evidencia del Avance 1, y luego evolucionarlo al SCARA completo (opción B) añadiendo el eje Z y el cabezal de doble efector. Los servos de bus serie se compran una sola vez y se reutilizan en ambas etapas.

05

## Diseño recomendado: SCARA de sobremesa

Las dimensiones no son arbitrarias. Se eligieron optimizando el condicionamiento del jacobiano sobre la trayectoria concreta de este equipo.

Vista superior del SCARA propuesto sobre la rosa de tres pétalos. Los tres colores codifican los tercios del parámetro t, igual que en la referencia física. Se muestran tres poses: punta del pétalo pequeño, punta del pétalo superior y paso por el origen. Las circunferencias punteadas azules marcan el anillo de trabajo efectivo (18,2–32,3 cm).

### Parámetros geométricos

Parámetro | Valor | Justificación
Eslabón 1 (hombro → codo) | L₁ = 200 mm | Eslabones iguales: simplifica la fabricación y sitúa el anillo de trabajo entre 0,46 y 0,81 del alcance total, lejos de ambas singularidades.
Eslabón 2 (codo → efector) | L₂ = 200 mm
Distancia base ↔ centro de la rosa | D = 220 mm | Optimizado. Mantiene θ₂ ∈ [72°, 126°] en toda la trayectoria: nunca se acerca al codo estirado (θ₂→0) ni al plegado (θ₂→180°).
Radio de trabajo | 182 – 323 mm | Todo el trazo cae dentro del anillo bien condicionado.
Número de condición máx. | cond(J) = 3,50 | Por debajo de 5 se considera bien condicionado. La amplificación de error es uniforme en toda la figura.
Carrera del eje Z | 60 mm | Suficiente para levantar el objeto, librar obstáculos y bajar a la zona de depósito.
Altura de eslabones sobre la mesa | 120 mm | Deja espacio para el cabezal y la carrera vertical.
Huella total | ≈ 520 × 460 mm | Cabe en un tablero de MDF de 60 × 50 cm cortado en el SPARK.

### Cinemática

Con la base del robot en el origen y el centro de la rosa desplazado a (D, 0):

Directa
x = L₁·cos θ₁ + L₂·cos(θ₁ + θ₂)
y = L₁·sin θ₁ + L₂·sin(θ₁ + θ₂)

Inversa (dos ramas: codo arriba / codo abajo)
cos θ₂ = (x² + y² − L₁² − L₂²) / (2·L₁·L₂)
θ₂ = ± atan2( √(1 − cos²θ₂), cos θ₂ )
θ₁ = atan2(y, x) − atan2( L₂·sin θ₂, L₁ + L₂·cos θ₂ )

Jacobiano
J = [ −L₁·s₁ − L₂·s₁₂ , −L₂·s₁₂ ]
[ L₁·c₁ + L₂·c₁₂ , L₂·c₁₂ ]
det J = L₁·L₂·sin θ₂ → singular cuando θ₂ = 0 o θ₂ = π

Para el informe de Cálculo III

La elección de rama (codo arriba en todo el recorrido) es una decisión de diseño con consecuencia física: cambiar de rama a mitad del trazo obligaría al brazo a atravesar la configuración singular θ₂ = 0, donde la velocidad articular tiende a infinito. Documentar esto con det J = L₁L₂ sin θ₂ y la gráfica de θ₂(t) sobre la trayectoria es justamente el tipo de argumento que pide el Avance 2 en «optimización y análisis de sensibilidad».

### Estructura y fabricación

- Eslabones: perfil de aluminio en U de 20 × 20 mm o tubo rectangular, no PLA macizo. Un eslabón impreso de 200 mm flexiona bajo carga lateral y ese error no se calibra. Alternativa: sándwich de dos placas de acrílico de 4 mm separadas por espaciadores, cortadas en láser en el SPARK: rígido y económico.
- Juntas: rodamiento axial de bolas en el hombro (soporta el momento flector) más rodamiento radial 608ZZ para el eje. El codo puede llevar solo 608ZZ dobles con separación de 20 mm entre ellos, lo que resiste el cabeceo.
- Piezas impresas en 3D: soportes de servo, cárter de reducción, cuerpo del cabezal. PLA+ o PETG al 40 % de relleno y 4 perímetros. Usar impresión donde la geometría es compleja, aluminio o acrílico donde manda la rigidez.
- Base: tablero de MDF de 15 mm, 60 × 50 cm, con la trayectoria de cartón fijada en posición conocida y referenciada por dos pines de origen. Sin repetibilidad en la colocación del papel, la calibración se pierde entre sesiones.
- Eje Z: husillo T8 con tuerca antibacklash y dos varillas lisas de 8 mm, movido por un servo de rotación continua o un NEMA 17 pequeño. Es el subsistema donde la precisión importa menos: solo necesita repetir arriba y abajo.

06

## Actuadores: la decisión más cara de revertir

Tres opciones reales, en orden de preferencia.

### 1 · Servo de bus serie Feetech STS3215 Recomendado

Es el servo del ecosistema SO-101 / LeRobot. Encóder magnético de 360° con 4 096 cuentas (0,088° por cuenta), 30 kg·cm a 12 V, comunicación semidúplex TTL encadenable: seis servos comparten un solo cable de datos. Precio unitario de 14 a 18 USD.

La ventaja decisiva no es el torque sino la realimentación: el servo reporta su posición real. Eso convierte el requisito R1, «control individual y verificable de cada servomotor», en una lectura directa, no en un argumento. Permite construir la gráfica de posición comandada frente a posición medida, que es evidencia de primera clase para los ciclos de «prueba, medición, análisis y ajuste» del entregable II de Física III.

### 2 · MG996R con reducción por correa 6:1

Si el presupuesto no da para servos de bus, la alternativa es una reducción GT2 de 6:1 entre el servo y la junta. La reducción divide la zona muerta por seis (de 1,5° a 0,25°) y multiplica el torque por seis. Costo: unos 12 USD por junta en poleas, correa y rodamientos.

Advertencia

La reducción también divide el rango angular. Un MG996R de 180° con reducción 6:1 solo da 30° en la junta. Para la rosa de tres pétalos se necesita bastante más. Hay dos salidas: reducción 3:1 con MG996R de 270° (rango de 90°, error 0,5° → 4,4 mm), o modificar el servo a rotación continua con potenciómetro externo en la junta, lo que ya es construir un servo propio. Verificar el rango articular requerido antes de comprometerse con esta ruta: es la trampa que hace fracasar la mitad de estos proyectos.

### 3 · NEMA 17 con correa y realimentación por encóder

Precisión sobrada (0,05 mm) y es lo que usa el SCARA de HowToMechatronics. El problema es R1: un stepper en lazo abierto no es un servomotor. Se puede salvar añadiendo un encóder magnético AS5600 en cada junta, con lo que se convierte en un servo de lazo cerrado real: solución técnicamente excelente, pero añade una capa de firmware considerable.

Criterio | STS3215 | MG996R + 3:1 | NEMA 17 + AS5600
Resolución angular | 0,088° | 0,50° | 0,006°
Error de trazo resultante | 0,77 mm | 4,4 mm | 0,05 mm
Realimentación de posición | Nativa | Ninguna | Añadida
Rango articular útil | 360° | 90° | Ilimitado
Cableado | 1 bus para todos | 1 PWM por servo | 4 hilos + I²C por eje
Costo por junta | USD 16 | USD 17 | USD 22
Esfuerzo de firmware | Bajo (librería) | Muy bajo | Alto
Cumple R1 | Sí, literal | Sí, sin verificar | Requiere argumentar

#### Verificación de torque

Peor caso: brazo extendido, carga de 70 g en la punta, más 250 g de cabezal y eslabón 2
τhombro = (mobj + mcabezal)·g·Ltotal ... pero en SCARA el eje es VERTICAL

En un SCARA la gravedad no produce torque en θ₁ ni θ₂.
El torque solo vence inercia y fricción:
τ ≈ I·α + τfricción ≈ 0,32 kg·m² · 2 rad/s² + 0,3 N·m ≈ 0,94 N·m ≈ 9,6 kg·cm
STS3215 entrega 30 kg·cm → factor de seguridad 3,1× ✓

En un brazo antropomórfico el mismo cálculo con la gravedad incluida da unos 25 kg·cm en el hombro, al límite del servo y con el error variando según la postura. Esa diferencia es el argumento físico central a favor del SCARA y merece una página del informe de Física III.

07

## Sensor de material (Física III)

Requisito R3: distinguir el material de dos objetos desconocidos y tomar solo el metálico. Un solo sensor de proximidad no basta, y aquí está el error que comete casi todo el mundo.

### Por qué un sensor solo no sirve

El sensor inductivo (LJ12A3-4-Z/BX) detecta únicamente conductores: genera un campo magnético alterno, induce corrientes de Foucault en el metal cercano, y la pérdida de energía resultante amortigua su oscilador. Si no se activa, la conclusión es ambigua: puede ser que el objeto sea plástico, o que esté a más de 4 mm.

El sensor capacitivo (LJC18A3-B-Z/BX) detecta cualquier material que altere la capacitancia de su placa sensora, incluidos plásticos, vidrio y líquidos. Se activa con ambos objetos, así que por sí solo tampoco discrimina.

Solución: tabla de verdad de dos sensores

Capacitivo | Inductivo | Conclusión | Acción
0 | 0 | No hay objeto | Seguir buscando
1 | 0 | Objeto no metálico | Ignorar
1 | 1 | Objeto metálico | Activar electroimán y transportar
0 | 1 | Estado imposible | Fallo de sensor → detener

El cuarto renglón no es adorno: es detección de fallo, y documentarlo demuestra diseño experimental deliberado.

### La física que hay que explicar (R8)

Inductivo · corrientes de Foucault
ε = −dΦB/dt (Faraday) · sentido opuesto (Lenz)
La disipación P = I²R en el conductor amortigua el tanque LC del sensor → cae la amplitud → dispara.
Selectivo a conductores. Alcance nominal 4 mm; menor en acero inoxidable y aluminio.

Capacitivo · permitividad del medio
C = ε₀·εr·A / d
Aire ε_r ≈ 1 · PLA ≈ 3 · vidrio ≈ 5 · agua ≈ 80.
Un objeto en el campo aumenta C y desplaza la frecuencia del oscilador RC → dispara.
Alcance ajustable 1–10 mm por potenciómetro.

Oportunidad de nota

El enunciado menciona explícitamente «el sensor capacitivo». Construir el sensor capacitivo en vez de comprarlo (dos placas de cobre y la librería CapacitiveSensor de Arduino, que mide el tiempo de carga de un RC) convierte el entregable en física medible: se puede levantar la curva de capacitancia frente a distancia para cada material y compararla con C = ε₀ε_rA/d. Es la diferencia entre usar un sensor y entenderlo, y es exactamente lo que califica el 5 % del entregable I.

#### Detalle eléctrico que no se puede omitir

Los sensores industriales LJ12A3 y LJC18A3 funcionan a 6–36 V y su salida entrega la misma tensión de alimentación. Conectarlos directamente a un pin de Arduino lo destruye. Se requiere un divisor resistivo (10 kΩ / 20 kΩ para pasar de 12 V a 4 V) o un optoacoplador, que además aísla galvánicamente la parte de potencia. La versión NPN, con resistencia de pull-up a 5 V, es la más sencilla de interfazar.

08

## Doble efector: pinza + electroimán

### Mecanismo de intercambio

Opción | Cómo funciona | Dif. | Evaluación
Torreta rotativa | Un servo SG90 gira 180° un disco con la pinza a un lado y el electroimán al otro. El cambio es automático, en menos de un segundo, sin intervención humana. | 2/5 | Recomendado Cumple «intercambiable» de la forma más fuerte: el robot lo hace solo. Suma unos 60 g al cabezal.
Acople rápido manual | Base con imanes o clip tipo bayoneta; el operador cambia la herramienta entre ciclos. Es lo que usa el EEZYbotARM Mk2. | 1/5 | Cabezal más ligero y sencillo, pero exige intervención humana en plena demostración.
Ambos fijos, desplazados | Pinza y electroimán montados en paralelo con una separación conocida; se compensa con un desplazamiento en la cinemática inversa. | 1/5 | Mecánicamente trivial y matemáticamente interesante (offset del efector en la IK), pero «intercambiable» queda forzado.

### Dimensionado del electroimán

Trampa de especificación

Los electroimanes se venden por fuerza de retención, medida con la pieza en contacto plano perfecto y sin entrehierro. La capacidad real de levantar un objeto es entre 5 y 10 veces menor, porque el contacto es imperfecto y hay componente de corte. Un electroimán de «2,5 kg» levanta con seguridad unos 250–500 g.

F = B²·A / (2·μ₀) μ₀ = 4π × 10⁻⁷ T·m/A

Requisito: 70 g → 0,687 N. Con factor de seguridad 3 (aceleración del brazo): 2,1 N
Aplicando el derateo de 5×: se necesita una retención nominal ≥ 10,5 N ≈ 1,1 kg
Elegir P20/15 (2,5 kg nominal) → margen holgado, 12 V, ≈ 0,3 A

Restricción física a documentar: solo funciona con materiales ferromagnéticos. Si el objeto «metálico» del ejercicio resultara ser de aluminio o cobre, el electroimán no lo levanta aunque el sensor inductivo sí lo detecte. Confirmar el material real del objeto antes de la semana 8. Es un riesgo de proyecto, no un detalle.

#### Circuito de accionamiento

El electroimán consume del orden de 300 mA a 12 V: no puede ir a un pin de Arduino. Se usa un MOSFET de nivel lógico (IRLZ44N o IRL540N) con la puerta al pin, resistencia de puerta de 220 Ω, pull-down de 10 kΩ, y diodo flyback 1N4007 en antiparalelo con la bobina. Sin ese diodo, la fem inducida al cortar la corriente (V = −L·di/dt, la misma ley de Faraday del sensor) genera un pico de decenas de voltios que destruye el MOSFET. Es la aplicación más directa del temario de Física III en todo el proyecto y merece medirse con osciloscopio.

### Pinza

Pinza paralela impresa en 3D con engranajes de piñón y cremallera, movida por un SG90 o MG90S. Diseños probados: la del EEZYbotARM Mk2 (con acople rápido, la mejor documentada) o la del brazo de HowToMechatronics. Añadir tacos de TPU o goma en las mordazas: un objeto de 70 g se resbala de PLA liso.

09

## Cadena MATLAB → Simulink → Arduino

El requisito R5 pide una simulación 3D en Simulink con la geometría real. Hay dos rutas de integración y elegir mal cuesta semanas.

| Ruta A · Simulink External Mode | Ruta B · MATLAB genera, Arduino ejecuta
Cómo | Simulink Support Package for Arduino Hardware compila el modelo y lo carga en el Arduino; External Mode permite ajustar parámetros y graficar señales en vivo. | MATLAB calcula la cinemática inversa fuera de línea y exporta la lista de ángulos articulares. El Arduino ejecuta un intérprete propio de esa lista.
A favor | Es literalmente lo que evalúa el enunciado. Sintonizar ganancias mientras el brazo se mueve es evidencia perfecta de los ciclos de prueba y ajuste. | Firmware más simple, ejecución determinista, funciona sin licencia de Simulink en el portátil del laboratorio.
En contra | Requiere licencia y paquete de soporte instalado. El código generado es más lento; hay que cuidar el tiempo de muestreo. | No hay lazo cerrado con Simulink en tiempo real; la simulación queda desacoplada del hardware.
| Usar para el Avance 2 y la defensa | Usar como respaldo

### Flujo recomendado

1. CAD primero. Modelar el SCARA completo en SolidWorks o Onshape antes de fabricar. Sin CAD no hay simulación válida, y R5 lo exige explícitamente.
2. Exportar a Simscape Multibody. El plugin Simscape Multibody Link exporta el ensamblaje de SolidWorks a XML más archivos de geometría; al importarlo, MATLAB genera los cuerpos con masas e inercias reales y convierte los mates del CAD en articulaciones. Esto entrega la simulación 3D casi gratis, con la geometría verdadera del prototipo.
3. Trayectoria en MATLAB. La herramienta mathbot_trayectoria.html que ya existe en el repositorio exporta los waypoints en CSV y en formato MATLAB. Alimentarlos al bloque de cinemática inversa.
4. Cerrar el lazo. Comparar la posición comandada con la que reportan los encóders de los STS3215. Esa gráfica de error es el corazón de la defensa final.

Decisión pendiente del README

El repositorio ya identifica esta bifurcación: si el firmware interpola en espacio articular (ángulo a ángulo entre waypoints), el camino cartesiano real se arquea y el error sube; hay que duplicar a 24–30 puntos por pétalo. Si interpola en espacio cartesiano (cinemática inversa punto a punto en una malla fina), bastan los 15 puntos adaptativos por pétalo. Recomendación: interpolación cartesiana. Los servos de bus serie aceptan comandos a más de 50 Hz, más que suficiente para resolver la IK en línea en un Arduino Mega o un ESP32.

10

## Lista de materiales y presupuesto

Supuestos de precio

Precios en USD de importación (AliExpress, Amazon) en agosto de 2026, sin arancel. La compra en tienda local de electrónica suele costar entre 30 % y 60 % más pero llega en días en lugar de semanas. La columna en pesos colombianos usa una tasa supuesta de COP 4 000 / USD y es orientativa; ajustar a la tasa y proveedor reales. Comprar los servos en la semana 1: son el artículo de plazo de entrega más largo y bloquean todo lo demás.

### Ruta recomendada · SCARA con servos de bus serie

Subsistema | Componente | Cant. | USD/u | USD | COP aprox.
Actuación | Servo bus serie Feetech STS3215 12 V, 30 kg·cm | 4 | 16 | 64 | 256 000
| Placa controladora de bus serie (Waveshare o similar) | 1 | 11 | 11 | 44 000
| Micro servo MG90S (torreta y pinza) | 2 | 4 | 8 | 32 000
Estructura | Perfil de aluminio 20×20 mm, 1 m | 2 | 7 | 14 | 56 000
| Rodamiento axial 51105 + radiales 608ZZ | 1 | 18 | 18 | 72 000
| Filamento PLA+ 1 kg (uso ≈ 500 g) | 1 | 20 | 20 | 80 000
| Tablero MDF 15 mm, 60×50 cm + tornillería M3/M4 | 1 | 24 | 24 | 96 000
Eje Z | Husillo T8 300 mm + tuerca antibacklash + acople | 1 | 14 | 14 | 56 000
| Varilla lisa 8 mm + rodamiento lineal LM8UU | 2 | 6 | 12 | 48 000
Sensado | Sensor inductivo LJ12A3-4-Z/BX NPN | 1 | 5 | 5 | 20 000
| Sensor capacitivo LJC18A3-B-Z/BX NPN | 1 | 7 | 7 | 28 000
| Lámina de cobre + resistencias (sensor capacitivo propio) | 1 | 6 | 6 | 24 000
Efector | Electroimán 12 V P20/15, retención 2,5 kg | 1 | 6 | 6 | 24 000
| MOSFET IRLZ44N, diodos 1N4007, resistencias | 1 | 4 | 4 | 16 000
Control | Arduino Mega 2560 (o ESP32) | 1 | 16 | 16 | 64 000
| Fuente conmutada 12 V 5 A + conector | 1 | 14 | 14 | 56 000
| Regulador 5 V, protoboard, cables, borneras | 1 | 12 | 12 | 48 000
| Paro de emergencia, portafusibles, cable | 1 | 10 | 10 | 40 000
Subtotal | | | | 265 | 1 060 000
Con 15 % de contingencia (repuestos, piezas rotas) | | | | 305 | 1 220 000

No incluye impresora 3D, cortadora láser ni herramienta: se asume acceso al SPARK.

### Comparación de las tres rutas de presupuesto

| Económica | Recomendada | Alta precisión
Actuadores θ₁, θ₂ | MG996R + reducción 3:1 | Feetech STS3215 | NEMA 17 + correa 20:1 + AS5600
Estructura | PLA impreso | Aluminio 20×20 + PLA | V-Slot 2020 + placas de acrílico
Error de trazo esperado | 4–6 mm | 2 mm | 0,3 mm
Precisión resultante | ≈ 96 % | ≈ 98,5 % | ≈ 99,8 %
Cumple R1 (servos verificables) | Parcial | Sí | Con argumento
Semanas de construcción | 5–6 | 7–9 | 10–12
Costo total con contingencia | USD 175 | USD 305 | USD 430
Aproximado en COP | 700 000 | 1 220 000 | 1 720 000

Dividido entre los integrantes del equipo, la ruta recomendada sale a unos USD 60–75 por persona en un grupo de cuatro o cinco.

Dónde sí vale la pena gastar de más

Los servos de θ₁ y θ₂ y los rodamientos del hombro. Son el 70 % del presupuesto de error y lo único que no se puede corregir después por software. Todo lo demás sí admite la versión barata sin consecuencias sobre la nota: Arduino, cables, filamento, sensores.

11

## Plan de trabajo por semanas

S1–2

Compras y medición

Pedir los servos el primer día (plazo de entrega largo). Medir el trazo físico en el SPARK y cerrar el pendiente abierto del README: confirmar k ≈ 1,355 contra la referencia real. Fijar por escrito el criterio de precisión.

S3–4

Avance 1 · Cálculo III · 7 %

Ecuación paramétrica justificada, dominio, orientación y escala, visualización en MATLAB y validación contra el cartón. En paralelo, montar el plotter polar (opción D) como banco de pruebas: dibujar la rosa con un lápiz demuestra el modelo con evidencia física, no solo con una gráfica.

S4–6

Entregable I · Física III · 5 %

Bitácora de alternativas: este documento es la base. CAD completo del SCARA en SolidWorks u Onshape. Control individual verificado de cada servo, con gráfica de posición comandada frente a medida. Caracterizar los dos sensores y levantar la tabla de verdad.

S6–9

Construcción del SCARA

Imprimir y cortar piezas, ensamblar juntas y eje Z, montar el cabezal de torreta. Calibrar el origen con los pines de referencia. Primera ejecución de la trayectoria completa y primera medición de error real.

S9–11

Simulación 3D

Exportar el CAD a Simscape Multibody, implementar la cinemática inversa en Simulink, validar la simulación contra el movimiento real. Análisis de sensibilidad y optimización de la trayectoria con restricciones de ingeniería.

S12

Avance 2 · Cálculo III · 3 %

Modelo actualizado con restricciones, simulación 3D funcionando, informe técnico breve y la pieza de comunicación del proyecto.

S12–16

Entregable II · Física III · 15 %

Ciclos documentados de prueba, medición, análisis y ajuste. Cada iteración con su gráfica de error antes y después. Aquí es donde la realimentación de los servos de bus serie paga su sobreprecio: cada ajuste queda cuantificado.

S17

Entrega final · Cálculo III · 5 %

Informe definitivo, demostración y defensa. Coherencia modelo ↔ simulación ↔ movimiento real, cuantificación del error, conclusiones y limitaciones.

Camino crítico

Las semanas 6 a 9 son el cuello de botella. Si el SCARA no ejecuta la trayectoria completa para el final de la semana 9, no queda tiempo para los ciclos de mejora que valen el 15 % de Física III. El plotter polar de la semana 3 existe precisamente para descubrir los problemas de firmware y cinemática antes de que estén en el camino crítico.

12

## Riesgos y mitigaciones

Riesgo | Prob. | Impacto | Mitigación
Los servos no llegan a tiempo | Media | Alto | Pedirlos en la semana 1. Tener un plan B con MG996R de tienda local que permita avanzar en el montaje mecánico con el mismo patrón de tornillos.
El objeto «metálico» no es ferromagnético | Baja | Alto | Confirmar el material con el docente antes de la semana 8. Si es aluminio, el electroimán no sirve y la pinza pasa a ser el efector principal.
El trazo físico no coincide con k = 1,355 | Media | Medio | Ya está señalado en el README. Medir en el SPARK en la semana 1; reajustar por mínimos cuadrados si difiere.
Flexión de eslabones mayor a la prevista | Media | Medio | Usar aluminio en lugar de PLA desde el principio. Medir la flexión con un comparador y una carga conocida antes de ensamblar.
Rango articular insuficiente (ruta con reducción) | Alta | Alto | Verificar el barrido angular requerido antes de comprar poleas. Con L = 200 mm y D = 220 mm, θ₂ recorre de 72° a 126°: se necesitan al menos 60° útiles en el codo.
Pérdida de calibración entre sesiones | Alta | Medio | Dos pines de origen en la base y finales de carrera en cada junta. Rutina de homing obligatoria al encender.
Licencia de Simulink no disponible en el laboratorio | Baja | Medio | Verificar la licencia de la universidad en la semana 2. Ruta B (§09) como respaldo.
El equipo confunde precisión matemática con precisión física | Media | Alto | Mantener separados los dos números en todo el informe: error de discretización del modelo (0,56 mm) y error de ejecución del sistema (≈ 2 mm). Cálculo III evalúa el primero, Física III el segundo.

13

## Fuentes consultadas

#### Referencias de construcción

- SCARA Robot · How To Mechatronics. 4 GDL, cuatro NEMA 17 con A4988 sobre CNC Shield v3, correas GT2 de 200–400 mm, husillo T8 de 400 mm, rodamientos axiales 40×60×13 y 35×52×12, servo MG996R en la pinza, fuente de 12 V 6 A. El autor documenta juego residual atribuido a la construcción en plástico y al backlash de las correas. howtomechatronics.com/projects/scara-robot-how-to-build-your-own-arduino-based-robot/
- DIY Arduino Robot Arm with Smartphone Control · How To Mechatronics. 5 GDL con tres MG996R y tres SG90, estructura en PLA, control por HC-05 y aplicación de MIT App Inventor. Referencia principal de la opción A. howtomechatronics.com/tutorials/arduino/diy-arduino-robot-arm-with-smartphone-control/
- EEZYbotARM Mk2 · Instructables. Brazo de cuatro ejes impreso en 3D, con cinemática de varillaje derivada del ABB IRB460 a escala 1:7. Aporta la pinza con acople rápido y el enrutado interno de cables. instructables.com/EEZYbotARM-Mk2-3D-Printed-Robot/
- OpenBuilds ACRO System. Pórtico XY en V-Slot; el kit mecánico comercial ronda los 1 739 EUR. Guía de conversión a plotter con GRBL y Universal G-code Sender publicada en Instructables. builds.openbuilds.com/builds/openbuilds-acro-system.5416/
- Fabri Creator. Kits de brazo robótico con envío internacional gratuito: Kit 4.0 USD 69, Kit 4.1 USD 79, Kit 5.0 USD 169, Mini USD 65. Documentación y soporte en español. fabricreator.com
- SO-101 / LeRobot. Brazo de código abierto con seis Feetech STS3215 de 12 V y 30 kg·cm, encóder magnético de 360°, bus TTL semidúplex encadenable; construcción DIY en torno a USD 150. STL, código y BOM públicos. github.com/maximilienroberti/lerobotdepot

#### Componentes y física

- Sensor inductivo LJ12A3-4-Z/BX. Alcance nominal 4 mm, 6–36 VDC. Detecta solo conductores; la salida entrega la tensión de alimentación y requiere adaptación de nivel para Arduino. electropeak.com/learn/interfacing-inductive-proximity-sensor-lj12a3-4-z-bx-with-arduino/
- Sensor capacitivo LJC18A3-B-Z/BX. Alcance ajustable 1–10 mm, 6–36 VDC. Detecta metales y no metales por variación de permitividad. docs.cirkitdesigner.com/component/ljc18a3-b-zby-capacitive-proximity-sensor
- Electroimanes de retención (Adafruit, serie P). P20/15 con 2,5 kg nominales, P25/20 con 5 kg, P30/22 con 10 kg. La documentación advierte explícitamente que hay que dividir la fuerza de retención entre 5 y 10 para estimar la capacidad real de levantar. adafruit.com/product/3872
- TowerPro MG996R. 15,5 kg·cm a 6 V. Repetibilidad pobre y zona muerta ancha frente a servos digitales; los foros de robótica reportan errores de posición de varios milímetros en brazos de esta escala. servodatabase.com/servo/towerpro/mg996r

#### Cadena de simulación

- Simscape Multibody Link para SolidWorks. Exporta el ensamblaje a XML más archivos de geometría; la importación en MATLAB genera cuerpos con masas e inercias y convierte los mates del CAD en articulaciones. mathworks.com/help/smlink/ug/export-robot-assembly-from-solidworks-software.html
- Simulink Support Package for Arduino Hardware. Bloques de servo, generación de código y External Mode para sintonizar parámetros con el hardware en marcha. mathworks.com/help/simulink/supportpkg/arduino_ref/servo-control.html

#### Documentos del proyecto

- MATHBOT, Semestre 2 2026. Enunciado oficial del PBL, 5 páginas. Fuente de todos los requisitos de §01. MATHBOT_-_Semestre_2_2026.pdf
- README del repositorio y herramienta de trayectoria. Origen de los parámetros A = 10,29 cm y k = 1,355, del análisis de discretización adaptativa y de los pendientes abiertos que este documento retoma. README.md · mathbot_trayectoria.html

Cálculos propios

Las extensiones de la curva, el radio máximo, el dimensionado de eslabones, el rango de θ₂, el número de condición del jacobiano y la amplificación de 8,70 mm por grado se calcularon para este documento sobre la parametrización del repositorio, evaluada en 1 201 puntos de t ∈ [0, π].

MATHBOT · Investigación de construcción · v1 Documento de trabajo · revisar antes del Entregable I

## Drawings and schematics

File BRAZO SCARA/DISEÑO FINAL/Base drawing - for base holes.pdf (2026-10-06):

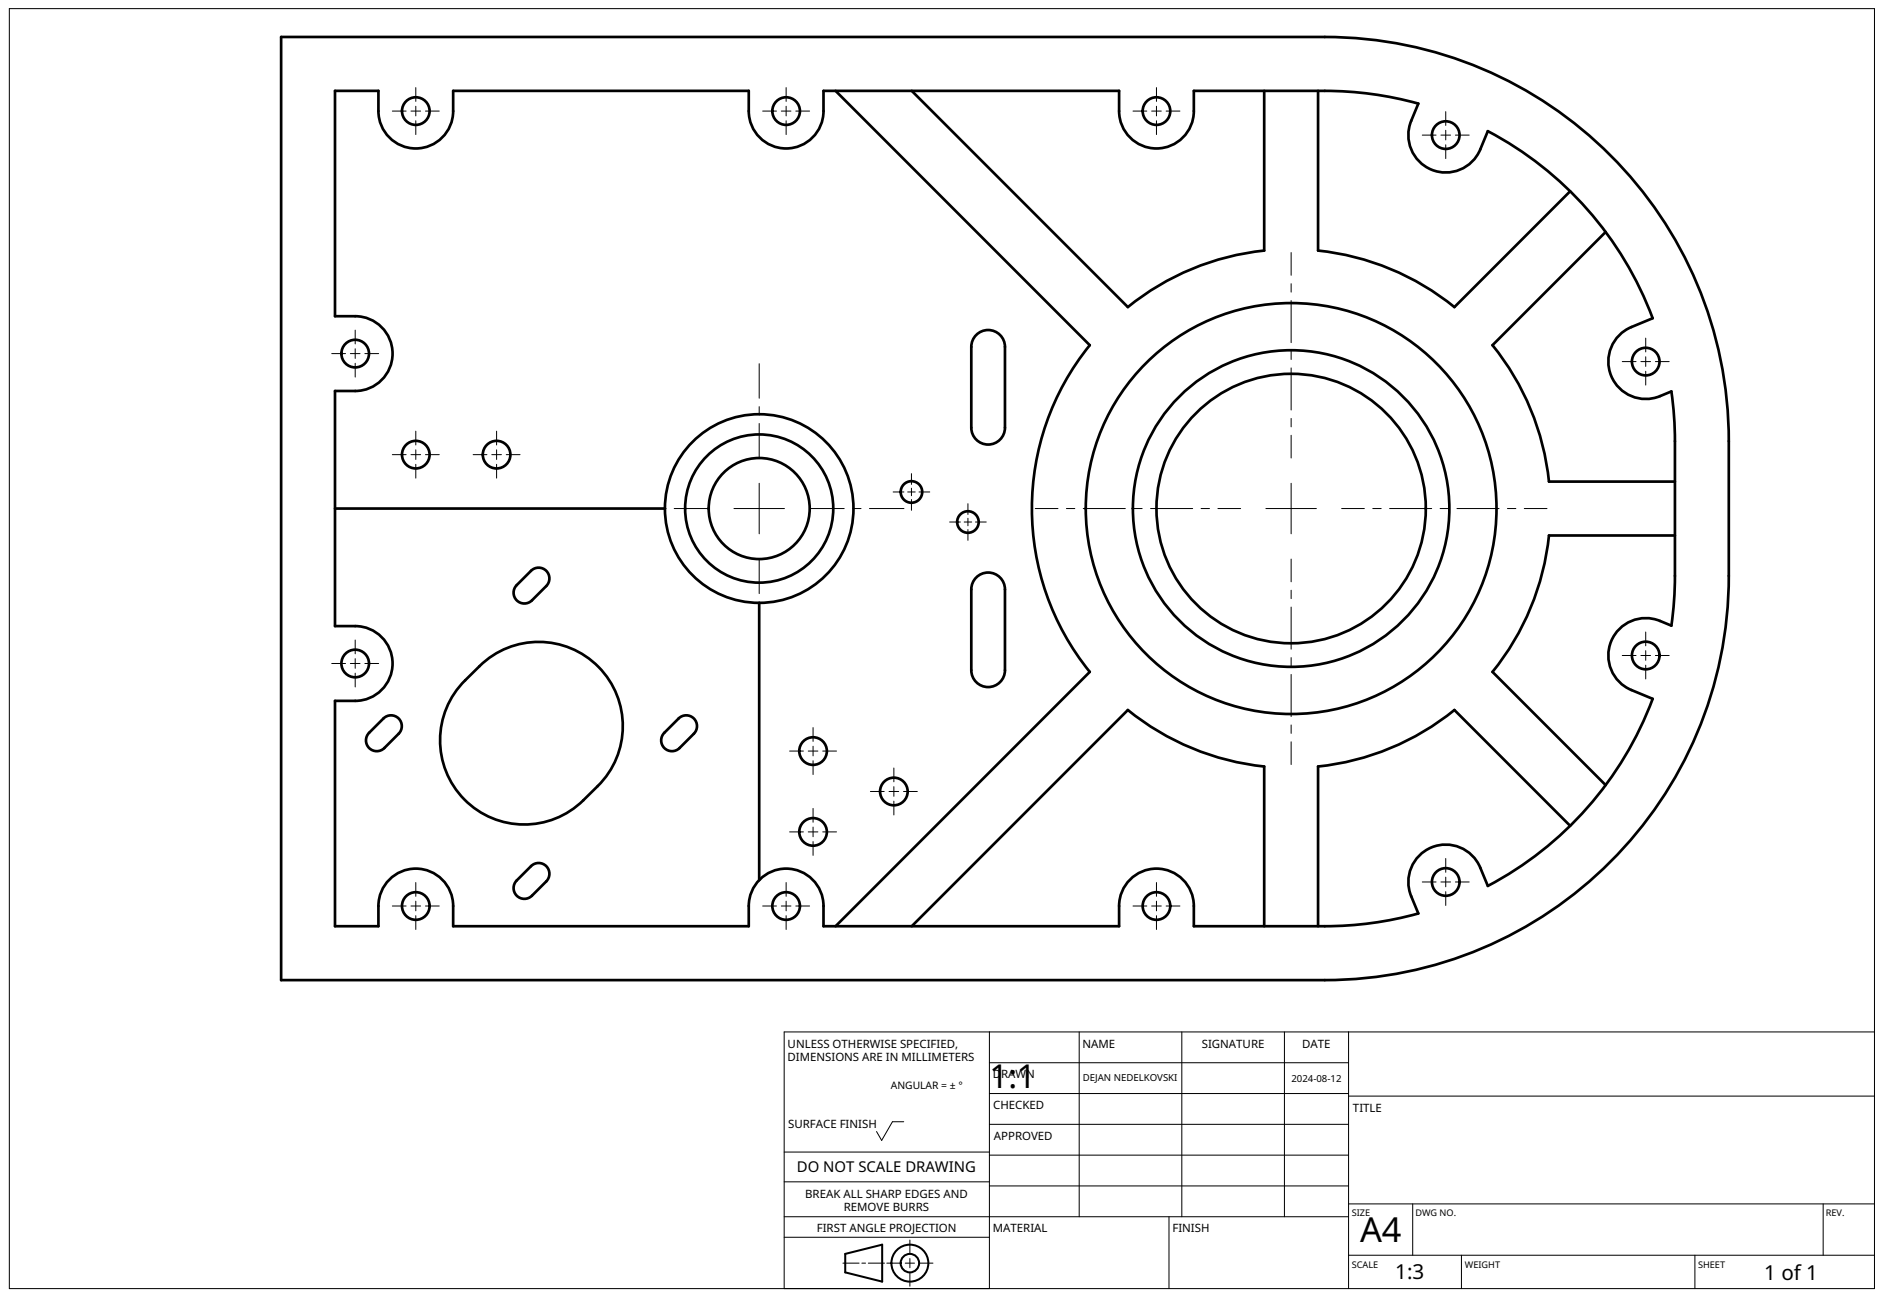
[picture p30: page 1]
MATERIAL; FINISH

UNLESS OTHERWISE SPECIFIED, DIMENSIONS ARE IN MILLIMETERS ANGULAR = ± ° SURFACE FINISH | | NAME | SIGNATURE | DATE

1:1 DRAWN | DEJAN NEDELKOVSKI | | 2024-08-12

CHECKED | | | | TITLE

APPROVED

DO NOT SCALE DRAWING

BREAK ALL SHARP EDGES AND

REMOVE BURRS
FIRST ANGLE PROJECTION

SIZE A4 | DWG NO. | REV.

SCALE 1:3 | WEIGHT | SHEET 1 of 1

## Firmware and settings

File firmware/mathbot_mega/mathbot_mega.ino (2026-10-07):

/*
  MathBot · firmware principal
  Arduino MEGA 2560 + CNC Shield V3 + 4 x A4988 (1/4 de micropaso: jumper solo en MS2)

  SCARA de HowToMechatronics con el cabezal A · disco tri-herramienta:
    plumón (phi 0°, r 55 mm), electroimán (phi 120°, r 45 mm), sensor inductivo (phi 240°, r 45 mm).
  J3 gira el disco para poner al frente la herramienta activa; un micro-servo SG90 sube/baja el plumón.

  La CNC Shield usa los mismos pines en el Mega que en el UNO (D2–D13, A0–A3), así que los motores y
  finales de carrera quedan igual que en el artículo. Todo lo nuevo va a los pines que el Mega tiene de
  más (header doble D22–D53 y A8–A15), sin tocar la shield.

  Comandos por Serial (115200 baudios, terminar con Enter):
    H              homing (Z, J3, J2, J1 como en HTM)
    S              saltar homing: toma la pose actual como home (banco de pruebas / Wokwi)
    ?              estado
    T p|i|s        herramienta activa: plumón, imán o sensor (gira J3)
    M x y          lleva la herramienta activa a (x, y) mm, movimiento articular
    L x y          línea recta a (x, y) mm a la velocidad de trazo
    Z z            altura de la plataforma (mm)
    A t1 t2 phi z  ángulos directos (grados, grados, grados, mm)
    V v            velocidad de trazo (mm/s)
    P 1|0          plumón abajo / arriba
    E 1|0          electroimán encendido / apagado
    D              dibujar la rosa de 3 pétalos
    X              escanear las piezas con el sensor
    R              misión completa: escaneo -> recolección -> rosa (también el botón START)
    O              desenergizar motores
    C              limpiar el paro de emergencia (obliga a repetir el homing)
    !              paro inmediato (también funciona en pleno movimiento)

  Bibliotecas: AccelStepper (Mike McCauley) y Servo (incluida en el IDE).
*/
#include <AccelStepper.h>
#include <Servo.h>
#include <math.h>

// ============================================================================
// Configuración
// ============================================================================
const bool SIMULACION = false;  // true en Wokwi: los finales de carrera son pulsadores NA

// ---- Pines de la CNC Shield V3 (idénticos en UNO y Mega) ----
const uint8_t PIN_ENABLE = 8;
const uint8_t J1_STEP = 2, J1_DIR = 5;   // ranura X
const uint8_t J2_STEP = 3, J2_DIR = 6;   // ranura Y
const uint8_t J3_STEP = 4, J3_DIR = 7;   // ranura Z  (como en HTM, J3 va en la ranura Z)
const uint8_t Z_STEP = 12, Z_DIR = 13;   // ranura A  (jumpers del eje A en D12/D13)
const uint8_t SW_J1 = 11;  // header Z+/Z-  (limitSwitch1 de HTM)
const uint8_t SW_J2 = 10;  // header Y+/Y-
const uint8_t SW_J3 = 9;   // header X+/X-
const uint8_t SW_Z = A3;   // header CoolEn

// ---- Pines extra del Mega ----
const uint8_t PIN_SENSOR = 22;    // salida del PC817 (LOW = metal)
const uint8_t PIN_IMAN = 24;      // gate del módulo MOSFET D4184
const uint8_t PIN_START = 26;     // pulsador NA a GND
const uint8_t PIN_PARO = 28;      // hongo NC a GND (abierto = paro)
const uint8_t LED_VERDE = 30;     // listo
const uint8_t LED_AMARILLO = 32;  // en movimiento
const uint8_t LED_ROJO = 34;      // paro / error
const uint8_t PIN_BUZZER = 36;
const uint8_t PIN_SERVO = 44;     // SG90 del levante del plumón
const uint8_t PIN_12V = A8;       // divisor 10k / 3.3k desde los 12 V
// Reservados: Serial1 (D18/D19) Bluetooth HC-05 o servos STS3215; I2C (D20/D21) AS5600 o LCD;
// Serial2 (D16/D17), Serial3 (D14/D15), D23–D53 impares y A9–A15 libres.

// ---- Geometría (python/scara_modelo.py) ----
const float L1 = 228.0, L2 = 144.0;
const float CAIDA_BRIDA = 78.5;  // base de la plataforma Z -> brida del cabezal
const float ESPESOR_DISCO = 6.0;
const int CODO = -1;             // theta2 negativo

struct Herramienta {
  const char *nombre;
  float phiDeg;   // posición en el disco
  float radio;    // distancia al eje J3 (mm)
  float bajo;     // cuánto sobresale bajo el disco (mm)
};
enum { PLUMON = 0, IMAN = 1, SENSOR = 2 };
const Herramienta HERR[3] = {
  { "plumon", 0.0, 55.0, 50.0 },
  { "electroiman", 120.0, 45.0, 40.0 },
  { "sensor", 240.0, 45.0, 38.0 },
};

// ---- Accionamiento: NEMA 17, 200 pasos x 1/4 ----
enum { EJE_J1 = 0, EJE_J2 = 1, EJE_J3 = 2, EJE_Z = 3 };
const char *NOMBRE_EJE[4] = { "J1", "J2", "J3", "Z" };
const float PASOS_UNIDAD[4] = { 44.4444, 35.5556, 10.0, 100.0 };  // pasos/grado, pasos/mm en Z
const float VMAX[4] = { 3000, 3000, 1500, 3500 };                  // pasos/s
const float ACEL[4] = { 2000, 2000, 1500, 3000 };                  // pasos/s²
const bool INVERTIR_DIR[4] = { false, false, false, false };       // si un eje gira al revés
const float LIM_MIN[4] = { -150, -150, -170, 103.5 };
const float LIM_MAX[4] = { 150, 150, 170, 203.0 };                 // Z: varillas de 250 mm

// ---- Homing: dónde queda cada final de carrera (valores del sketch de HTM, CALIBRAR) ----
const float HOME_POS[4] = { -89.0, -152.4, -166.2, 203.0 };
const int HOME_SENTIDO[4] = { -1, -1, -1, +1 };       // J1–J3 hacia negativo, Z hacia arriba
const float HOME_VEL[4] = { 1200, 1300, 1100, 1500 };  // pasos/s
const float HOME_RECORRIDO_MAX[4] = { 320, 320, 360, 120 };  // si no toca el final -> error

// ---- Plumón ----
const int SERVO_ABAJO = 20;    // grados; calibrar con prueba_servo
const int SERVO_ARRIBA = 110;  // levanta 18 mm

// ---- Escena de la misión (mismas coordenadas que el simulador) ----
struct Pieza { const char *nombre; float x, y, h; };
const Pieza PIEZAS[4] = {
  { "pieza 1", 60, -215, 3 },
  { "pieza 2", 150, -238, 8 },
  { "pieza 3", 240, -215, 7 },
  { "pieza 4", 325, -172, 12 },
};
const float BANDEJA_X = 95, BANDEJA_Y = 235, BANDEJA_H = 25;
const float Z_TIP_VIAJE = 60;  // altura de la punta en tránsito (mm sobre la mesa)

// ---- Rosa de 3 pétalos ----
const float ROSA_A = 102.9, ROSA_K = 1.3552;
const float ROSA_T0 = 5 * M_PI / 6, ROSA_T1 = 11 * M_PI / 6;
const float ROSA_CX = 185.0, ROSA_CY = 0.0, ROSA_ALFA = M_PI;  // centrada a 185 mm, girada 180°
const float SEG_MM = 1.0;  // largo de cada tramo recto del trazo

// ============================================================================
// Estado
// ============================================================================
AccelStepper motor[4] = {
  AccelStepper(AccelStepper::DRIVER, J1_STEP, J1_DIR),
  AccelStepper(AccelStepper::DRIVER, J2_STEP, J2_DIR),
  AccelStepper(AccelStepper::DRIVER, J3_STEP, J3_DIR),
  AccelStepper(AccelStepper::DRIVER, Z_STEP, Z_DIR),
};
const uint8_t PIN_FINAL[4] = { SW_J1, SW_J2, SW_J3, SW_Z };
Servo servoPluma;

bool homeHecho = false;
bool enParo = false;
int herrActiva = PLUMON;
float xAct = NAN, yAct = NAN;  // punta de la herramienta activa
float velTrazo = 25.0;         // mm/s
bool piezaMetal[4] = { false, false, false, false };
bool escaneoHecho = false;

// ============================================================================
// Utilidades
// ============================================================================
float envolver(float a) {
  while (a > 180) a -= 360;
  while (a <= -180) a += 360;
  return a;
}

long aPasos(int eje, float v) { return lround(v * PASOS_UNIDAD[eje]); }
float aUnidad(int eje, long p) { return p / PASOS_UNIDAD[eje]; }
float posicion(int eje) { return aUnidad(eje, motor[eje].currentPosition()); }

bool finalActivo(uint8_t pin) {
  // Real: final NC entre pin y GND (como HTM), activo = abierto = HIGH. Wokwi: pulsador NA, activo = LOW.
  return digitalRead(pin) == (SIMULACION ? LOW : HIGH);
}

bool hayMetal() {
  int votos = 0;
  for (int i = 0; i < 20; i++) {
    if (digitalRead(PIN_SENSOR) == LOW) votos++;
    delay(10);
  }
  return votos > 10;
}

float voltaje12() {
  return analogRead(PIN_12V) * (5.0 / 1023.0) * (13.3 / 3.3);
}

void leds(bool verde, bool amarillo, bool rojo) {
  digitalWrite(LED_VERDE, verde);
  digitalWrite(LED_AMARILLO, amarillo);
  digitalWrite(LED_ROJO, rojo);
}

void pitido(int f, int ms) { tone(PIN_BUZZER, f, ms); }

void motores(bool on) { digitalWrite(PIN_ENABLE, on ? LOW : HIGH); }

void pluma(bool abajo) {
  servoPluma.write(abajo ? SERVO_ABAJO : SERVO_ARRIBA);
  delay(300);
}

void iman(bool on) { digitalWrite(PIN_IMAN, on ? HIGH : LOW); }

// Altura de la plataforma para que la punta de la herramienta k quede a ztip sobre la mesa.
// El plumón se calcula bajado; con el plumón arriba su punta queda 18 mm más alta.
float zPlataforma(float ztip, int k) {
  return ztip + CAIDA_BRIDA + ESPESOR_DISCO + HERR[k].bajo;
}

// ============================================================================
// Paro de emergencia
// ============================================================================
void dispararParo(const char *motivo) {
  if (enParo) return;
  enParo = true;
  homeHecho = false;
  for (int i = 0; i < 4; i++) motor[i].setCurrentPosition(motor[i].currentPosition());
  motores(false);
  iman(false);
  leds(false, false, true);
  pitido(2000, 600);
  Serial.print(F("!! PARO: "));
  Serial.println(motivo);
  Serial.println(F("   Suelta el hongo y envia C; luego repite H."));
}

// Se llama dentro de todos los bucles de movimiento.
bool sigue() {
  if (digitalRead(PIN_PARO) == HIGH) dispararParo("boton de paro");
  if (Serial.available() && Serial.peek() == '!') {
    Serial.read();
    dispararParo("comando !");
  }
  return !enParo;
}

// ============================================================================
// Cinemática
// ============================================================================
bool dentroLimites(const float q[4]) {
  for (int i = 0; i < 4; i++)
    if (q[i] < LIM_MIN[i] || q[i] > LIM_MAX[i]) return false;
  return true;
}

// IK de la punta de la herramienta k con el disco girado para tenerla al frente (phi = -phi_k):
// la herramienta queda en la línea de Arm 2, así que Arm 2 "mide" L2 + r.
bool ik(float x, float y, int k, float &th1, float &th2) {
  float le = L2 + HERR[k].radio;
  float c2 = (x * x + y * y - L1 * L1 - le * le) / (2 * L1 * le);
  if (c2 < -1 || c2 > 1) return false;
  for (int intento = 0; intento < 2; intento++) {
    int codo = intento == 0 ? CODO : -CODO;
    float t2 = codo * acos(c2);
    float t1 = atan2(y, x) - atan2(le * sin(t2), L1 + le * cos(t2));
    th1 = envolver(degrees(t1));
    th2 = envolver(degrees(t2));
    if (th1 >= LIM_MIN[0] && th1 <= LIM_MAX[0] && th2 >= LIM_MIN[1] && th2 <= LIM_MAX[1]) return true;
  }
  return false;
}

float phiHerramienta(int k) { return envolver(-HERR[k].phiDeg); }

// ============================================================================
// Movimiento
// ============================================================================
void limpiarVelocidades() {
  for (int i = 0; i < 4; i++) motor[i].setCurrentPosition(motor[i].currentPosition());
}

// Movimiento articular con perfiles trapezoidales escalados para que los 4 ejes terminen a la vez.
bool moverArticular(float th1, float th2, float phi, float z) {
  float q[4] = { th1, th2, phi, z };
  if (!dentroLimites(q)) {
    Serial.println(F("   fuera de los limites articulares"));
    return false;
  }
  if (!sigue()) return false;
  limpiarVelocidades();
  long d[4];
  int ref = 0;
  float tMax = 0;
  for (int i = 0; i < 4; i++) {
    d[i] = labs(aPasos(i, q[i]) - motor[i].currentPosition());
    float t = d[i] / VMAX[i];
    if (t > tMax) { tMax = t; ref = i; }
  }
  if (d[ref] == 0) return true;
  for (int i = 0; i < 4; i++) {
    float k = (float)d[i] / d[ref];
    motor[i].setMaxSpeed(max(1.0f, VMAX[ref] * k));
    motor[i].setAcceleration(max(1.0f, ACEL[ref] * k));
    motor[i].moveTo(aPasos(i, q[i]));
  }
  leds(false, true, false);
  uint16_t n = 0;
  bool corriendo = true;
  while (corriendo) {
    corriendo = false;
    for (int i = 0; i < 4; i++) corriendo |= motor[i].run();
    if ((++n & 63) == 0 && !sigue()) return false;
  }
  leds(homeHecho, false, false);
  return true;
}

bool moverZ(float z) { return moverArticular(posicion(EJE_J1), posicion(EJE_J2), posicion(EJE_J3), z); }

// Tramo a velocidad constante (sin rampa): los ejes llegan a la vez en T segundos.
bool tramo(const long obj[4], float T) {
  for (int i = 0; i < 4; i++) {
    long d = obj[i] - motor[i].currentPosition();
    motor[i].moveTo(obj[i]);
    motor[i].setMaxSpeed(VMAX[i]);
    motor[i].setSpeed(min(VMAX[i], fabs(d / T)) * (d >= 0 ? 1 : -1));
  }
  uint16_t n = 0;
  bool corriendo = true;
  while (corriendo) {
    corriendo = false;
    for (int i = 0; i < 4; i++) {
      if (motor[i].distanceToGo() != 0) {
        motor[i].runSpeedToPosition();
        corriendo = true;
      }
    }
    if ((++n & 63) == 0 && !sigue()) return false;
  }
  return true;
}

// Lleva la punta de la herramienta activa a (x, y) en movimiento articular, a la altura actual.
bool irA(float x, float y) {
  float t1, t2;
  if (!ik(x, y, herrActiva, t1, t2)) {
    Serial.print(F("   fuera de alcance: "));
    Serial.print(x); Serial.print(F(", ")); Serial.println(y);
    return false;
  }
  if (!moverArticular(t1, t2, phiHerramienta(herrActiva), posicion(EJE_Z))) return false;
  xAct = x; yAct = y;
  return true;
}

// Interpolación cartesiana: un tramo de IK cada SEG_MM.
bool tramoRecto(float x, float y) {
  if (isnan(xAct)) return irA(x, y);
  float dx = x - xAct, dy = y - yAct, largo = hypot(dx, dy);
  int n = max(1, (int)ceil(largo / SEG_MM));
  float x0 = xAct, y0 = yAct;
  for (int i = 1; i <= n; i++) {
    if (!puntoTrazo(x0 + dx * i / n, y0 + dy * i / n)) return false;
  }
  limpiarVelocidades();
  return true;
}

// Un punto del trazo, desde la punta actual, a velTrazo.
bool puntoTrazo(float x, float y) {
  float t1, t2;
  if (!ik(x, y, herrActiva, t1, t2)) {
    Serial.print(F("   punto fuera de alcance: "));
    Serial.print(x); Serial.print(F(", ")); Serial.println(y);
    return false;
  }
  long obj[4] = { aPasos(EJE_J1, t1), aPasos(EJE_J2, t2), motor[EJE_J3].currentPosition(), motor[EJE_Z].currentPosition() };
  float T = max(hypot(x - xAct, y - yAct) / velTrazo, 0.002f);
  if (!tramo(obj, T)) return false;
  xAct = x; yAct = y;
  return true;
}

bool seleccionarHerramienta(int k) {
  if (k != PLUMON) pluma(false);
  herrActiva = k;
  if (!moverArticular(posicion(EJE_J1), posicion(EJE_J2), phiHerramienta(k), posicion(EJE_Z))) return false;
  xAct = yAct = NAN;  // la punta cambió; el siguiente movimiento parte por IK
  Serial.print(F("   herramienta activa: "));
  Serial.println(HERR[k].nombre);
  return true;
}

// ============================================================================
// Homing
// ============================================================================
bool homeEje(int e) {
  Serial.print(F("   homing "));
  Serial.println(NOMBRE_EJE[e]);
  motor[e].setCurrentPosition(0);
  motor[e].setMaxSpeed(HOME_VEL[e]);
  motor[e].setSpeed(HOME_SENTIDO[e] * HOME_VEL[e]);
  long limite = aPasos(e, HOME_RECORRIDO_MAX[e]);
  uint16_t n = 0;
  while (!finalActivo(PIN_FINAL[e])) {
    motor[e].runSpeed();
    if ((++n & 63) == 0 && !sigue()) return false;
    if (labs(motor[e].currentPosition()) > limite) {
      Serial.print(F("   ERROR: el final de "));
      Serial.print(NOMBRE_EJE[e]);
      Serial.println(F(" no se activo. Revisa cableado, 12 V y sentido del motor."));
      leds(false, false, true);
      pitido(400, 800);
      return false;
    }
  }
  motor[e].setCurrentPosition(aPasos(e, HOME_POS[e]));
  return true;
}

bool homing() {
  if (enParo) { Serial.println(F("   primero limpia el paro (C)")); return false; }
  if (voltaje12() < 10.5) Serial.println(F("   AVISO: no detecto los 12 V; los motores no van a moverse."));
  motores(true);
  pluma(false);
  iman(false);
  leds(false, true, false);
  const int orden[4] = { EJE_Z, EJE_J3, EJE_J2, EJE_J1 };
  for (int i = 0; i < 4; i++) {
    if (!homeEje(orden[i])) return false;
    if (orden[i] == EJE_Z) {
      // Z arriba primero para que el brazo no barra nada al buscar los otros finales
      if (!moverArticular(posicion(0), posicion(1), posicion(2), zPlataforma(Z_TIP_VIAJE, IMAN))) return false;
    }
  }
  homeHecho = true;
  herrActiva = PLUMON;
  if (!moverArticular(0, 0, 0, zPlataforma(Z_TIP_VIAJE, IMAN))) return false;
  xAct = yAct = NAN;
  leds(true, false, false);
  pitido(1500, 120);
  Serial.println(F("   homing listo"));
  return true;
}

void saltarHoming() {
  float q[4] = { 0, 0, 0, zPlataforma(Z_TIP_VIAJE, IMAN) };
  for (int i = 0; i < 4; i++) motor[i].setCurrentPosition(aPasos(i, q[i]));
  motores(true);
  homeHecho = true;
  herrActiva = PLUMON;
  xAct = yAct = NAN;
  leds(true, false, false);
  Serial.println(F("   pose actual tomada como home (th1 = th2 = phi = 0)"));
}

// ============================================================================
// Rutinas
// ============================================================================
void rosaPunto(float t, float &x, float &y) {
  float r = cos(3 * t);
  float xl = -ROSA_A * r * cos(t);
  float yl = -ROSA_A * ROSA_K * r * sin(t);
  x = ROSA_CX + cos(ROSA_ALFA) * xl - sin(ROSA_ALFA) * yl;
  y = ROSA_CY + sin(ROSA_ALFA) * xl + cos(ROSA_ALFA) * yl;
}

bool dibujarRosa() {
  Serial.println(F("== Rosa de 3 petalos con plumon =="));
  float x, y;
  rosaPunto(ROSA_T0, x, y);
  if (!seleccionarHerramienta(PLUMON)) return false;
  if (!irA(x, y)) return false;
  pluma(true);
  if (!moverZ(zPlataforma(8, PLUMON))) return false;
  if (!moverZ(zPlataforma(0, PLUMON))) return false;

  const int N = 4000;
  float total = 0;
  unsigned long t0 = millis();
  for (int i = 1; i <= N; i++) {
    float px, py;
    rosaPunto(ROSA_T0 + (ROSA_T1 - ROSA_T0) * i / N, px, py);
    float d = hypot(px - xAct, py - yAct);
    if (d >= SEG_MM || i == N) {
      if (!puntoTrazo(px, py)) return false;
      total += d;
    }
  }
  limpiarVelocidades();
  if (!moverZ(zPlataforma(10, PLUMON))) return false;
  pluma(false);
  if (!moverZ(zPlataforma(Z_TIP_VIAJE, IMAN))) return false;
  Serial.print(F("   rosa terminada: "));
  Serial.print(total, 0);
  Serial.print(F(" mm en "));
  Serial.print((millis() - t0) / 1000.0, 1);
  Serial.println(F(" s"));
  return true;
}

bool escanear() {
  Serial.println(F("== Fase 1: escaneo con sensor inductivo =="));
  if (!seleccionarHerramienta(SENSOR)) return false;
  for (int i = 0; i < 4; i++) {
    if (!moverZ(zPlataforma(Z_TIP_VIAJE, IMAN))) return false;
    if (!irA(PIEZAS[i].x, PIEZAS[i].y)) return false;
    if (!moverZ(zPlataforma(PIEZAS[i].h + 3, SENSOR))) return false;  // 3 mm sobre la pieza
    delay(300);
    piezaMetal[i] = hayMetal();
    Serial.print(F("   "));
    Serial.print(PIEZAS[i].nombre);
    Serial.println(piezaMetal[i] ? F(": METALICA") : F(": no metalica"));
    if (piezaMetal[i]) pitido(1800, 80);
  }
  escaneoHecho = true;
  return moverZ(zPlataforma(Z_TIP_VIAJE, IMAN));
}

bool recolectar() {
  Serial.println(F("== Fase 2: recoleccion con electroiman =="));
  if (!escaneoHecho) { Serial.println(F("   primero escanea (X)")); return false; }
  if (!seleccionarHerramienta(IMAN)) return false;
  int lugar = 0;
  for (int i = 0; i < 4; i++) {
    if (!piezaMetal[i]) continue;
    if (!irA(PIEZAS[i].x, PIEZAS[i].y)) return false;
    if (!moverZ(zPlataforma(PIEZAS[i].h + 0.5, IMAN))) return false;
    iman(true);
    delay(500);
    Serial.print(F("   iman ON -> levanta "));
    Serial.println(PIEZAS[i].nombre);
    if (!moverZ(zPlataforma(Z_TIP_VIAJE, IMAN))) return false;
    float bx = BANDEJA_X + (lugar % 2 ? 14 : -14);
    float by = BANDEJA_Y + (lugar < 2 ? -10 : 10);
    lugar++;
    if (!irA(bx, by)) return false;
    if (!moverZ(zPlataforma(BANDEJA_H + PIEZAS[i].h + 6, IMAN))) return false;
    iman(false);
    delay(400);
    Serial.println(F("   iman OFF -> pieza en la bandeja"));
    if (!moverZ(zPlataforma(Z_TIP_VIAJE, IMAN))) return false;
  }
  return true;
}

bool mision() {
  if (!homeHecho) { Serial.println(F("   primero haz homing (H) o S")); return false; }
  unsigned long t0 = millis();
  if (!escanear() || !recolectar() || !dibujarRosa()) return false;
  Serial.println(F("== Regreso a home =="));
  if (!seleccionarHerramienta(PLUMON)) return false;
  if (!moverArticular(0, 0, 0, zPlataforma(Z_TIP_VIAJE, IMAN))) return false;
  Serial.print(F("== Mision completa en "));
  Serial.print((millis() - t0) / 1000.0, 1);
  Serial.println(F(" s =="));
  pitido(1500, 100); delay(150); pitido(2000, 150);
  return true;
}

void estado() {
  Serial.println(F("---- estado ----"));
  Serial.print(F("home: ")); Serial.print(homeHecho ? F("si") : F("no"));
  Serial.print(F("   paro: ")); Serial.println(enParo ? F("SI") : F("no"));
  for (int i = 0; i < 4; i++) {
    Serial.print(NOMBRE_EJE[i]); Serial.print(F(" = ")); Serial.print(posicion(i), 2);
    Serial.print(i == EJE_Z ? F(" mm") : F(" deg"));
    Serial.print(F("   final: ")); Serial.println(finalActivo(PIN_FINAL[i]) ? F("ACTIVO") : F("libre"));
  }
  Serial.print(F("herramienta: ")); Serial.print(HERR[herrActiva].nombre);
  Serial.print(F("   punta: ")); Serial.print(xAct, 1); Serial.print(F(", ")); Serial.println(yAct, 1);
  Serial.print(F("sensor: ")); Serial.print(digitalRead(PIN_SENSOR) == LOW ? F("METAL") : F("nada"));
  Serial.print(F("   iman: ")); Serial.print(digitalRead(PIN_IMAN) ? F("ON") : F("off"));
  Serial.print(F("   12 V: ")); Serial.print(voltaje12(), 1); Serial.println(F(" V"));
  Serial.print(F("velocidad de trazo: ")); Serial.print(velTrazo, 0); Serial.println(F(" mm/s"));
}
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
void loop() {
  static char buf[48];
  static uint8_t len = 0;

  if (digitalRead(PIN_PARO) == HIGH) dispararParo("boton de paro");

  while (Serial.available()) {
    char ch = Serial.read();
    if (ch == '!') { dispararParo("comando !"); len = 0; continue; }
    if (ch == '\n' || ch == '\r') {
      buf[len] = 0;
      if (len) ejecutar(buf);
      len = 0;
    } else if (len < sizeof(buf) - 1) {
      buf[len++] = ch;
    }
  }

  if (digitalRead(PIN_START) == LOW && !enParo) {
    delay(30);
    while (digitalRead(PIN_START) == LOW) {}
    if (!homeHecho) homing();
    if (homeHecho) mision();
  }
}

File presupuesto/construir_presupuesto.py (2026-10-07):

"""
Genera presupuesto/MathBot_Presupuesto_SCARA.xlsx: lista de materiales del SCARA de
HowToMechatronics + cabezal de disco (versión final), con precios locales (El Salvador)
y de Amazon puestos en el país, estado de compra, registro de gastos e impresión 3D.

Uso (desde la raíz del repo):
    python presupuesto/construir_presupuesto.py
"""

from __future__ import annotations

import json
import os

from openpyxl import Workbook
from openpyxl.chart import BarChart, Reference
from openpyxl.comments import Comment
from openpyxl.formatting.rule import CellIsRule, FormulaRule
from openpyxl.styles import Alignment, Border, Font, PatternFill, Side
from openpyxl.utils import get_column_letter
from openpyxl.workbook.defined_name import DefinedName
from openpyxl.worksheet.datavalidation import DataValidation

AQUI = os.path.dirname(os.path.abspath(__file__))
import sys
SALIDA = sys.argv[1] if len(sys.argv) > 1 else os.path.join(AQUI, "MathBot_Presupuesto_SCARA.xlsx")
FECHA = "06-oct-2026"

# ---------------------------------------------------------------------------
# Estilos
# ---------------------------------------------------------------------------
F = "Arial"
f_base = Font(name=F, size=10)
f_bold = Font(name=F, size=10, bold=True)
f_title = Font(name=F, size=16, bold=True, color="1F3A5F")
f_sub = Font(name=F, size=10, italic=True, color="5B6876")
f_head = Font(name=F, size=10, bold=True, color="FFFFFF")
f_input = Font(name=F, size=10, color="0000FF")
f_link = Font(name=F, size=10, color="008000")
f_url = Font(name=F, size=9, color="1F6FD1", underline="single")
f_note = Font(name=F, size=9, color="5B6876")
f_ex = Font(name=F, size=10, italic=True, color="7F8C8D")
fill_head = PatternFill("solid", fgColor="1F3A5F")
fill_input = PatternFill("solid", fgColor="FFF2CC")
fill_cat = PatternFill("solid", fgColor="E3EEFB")
fill_tot = PatternFill("solid", fgColor="D9E2EC")
fill_kpi = PatternFill("solid", fgColor="F3F5F8")
thin = Side(style="thin", color="C9D3DD")
borde = Border(left=thin, right=thin, top=thin, bottom=thin)
USD = '$#,##0.00;($#,##0.00);"-"'
USD0 = '$#,##0;($#,##0);"-"'
PCT = '0.0%;(0.0%);"-"'
wrap = Alignment(wrap_text=True, vertical="top")
center = Alignment(horizontal="center", vertical="top")

ESTADOS = ["Por comprar", "Cotizado", "Comprado", "Ya lo tenemos", "No comprar"]
FUENTES = ["Local", "Amazon"]
PRIORIDADES = ["Obligatorio", "Recomendado", "Opcional"]
CATEGORIAS = [
    "Estructura y eje Z", "Rodamientos", "Transmisión", "Motores y electrónica",
    "Cabezal de disco", "Electrónica MathBot", "Tornillería", "Impresión y varios",
]


def amz(asin: str) -> str:
    return f"https://www.amazon.com/dp/{asin}" if asin and not asin.startswith("http") else asin


# ---------------------------------------------------------------------------
# Lista de materiales. Precios por PAQUETE; unidades por paquete aparte.
#   (id, categoria, componente, especificacion, uso, origen, cantidad, prioridad,
#    tienda_local, precio_local, unid_local, verif_local,
#    precio_amazon, unid_amazon, peso_lb, fuente, asin/url, notas)
# cantidad/precio pueden ser fórmulas (str que empieza con "=").
# ---------------------------------------------------------------------------
ITEMS = [
    # Estructura y eje Z
    ("MEC-01", "Estructura y eje Z", "Varilla lisa Ø10 mm", "Acero endurecido, 300 mm (cortar)", "4 guías de la columna Z",
     "HTM", 4, "Obligatorio", "Creativo 3D (repuestos de impresoras)", 8.00, 1, "Cotizar (estimado)",
     17.99, 4, 1.8, "Amazon", "B0D2312R72",
     "HTM usa 400 mm. Con el cabezal de disco bastan 240 mm (NEMA estándar en J2) o 220 mm (NEMA corto): comprar 300 y cortar."),
    ("MEC-02", "Estructura y eje Z", "Rodamiento lineal LM10UU", "10 × 19 × 29 mm", "Plataforma Z (desliza en las varillas)",
     "HTM", 4, "Obligatorio", "Creativo 3D / CEROSA", 3.00, 1, "Cotizar (estimado)",
     7.49, 4, 0.25, "Amazon", "B0D5BHVY9W", ""),
    ("MEC-03", "Estructura y eje Z", "Husillo T8 con tuerca de latón", "Tr8×8, 300 mm (avance 8 mm/rev)", "Eje Z",
     "HTM", 1, "Obligatorio", "Creativo 3D", 15.00, 1, "Cotizar (estimado)",
     11.99, 2, 0.6, "Amazon", "B08JPPC1TZ",
     "HTM lo corta a 380 mm para varillas de 400; con varillas de 240 mm cortar a ≈225 mm. El paquete trae 2."),
    ("MEC-04", "Estructura y eje Z", "Acople flexible 5 → 8 mm", "Aluminio", "Motor Z → husillo",
     "HTM", 1, "Obligatorio", "Creativo 3D", 5.00, 1, "Cotizar (estimado)",
     9.99, 5, 0.25, "Amazon", "B07JL1QYLS", ""),
    ("MEC-05", "Estructura y eje Z", "Base de madera o MDF 18–20 mm", "≈ 30 × 25 cm", "Fijar la base del robot (12 agujeros)",
     "HTM", 1, "Recomendado", "Almacenes Vidrí", 6.00, 1, "Estimado",
     None, None, None, "Local", "", "El artículo atornilla la base a madera de 20 mm y la sujeta a la mesa con prensas."),
    # Rodamientos
    ("ROD-01", "Rodamientos", "Rodamiento axial 51108", "40 × 60 × 13 mm", "J1 (uno a cada lado de la base)",
     "HTM", 2, "Obligatorio", "CEROSA / RODASA / REPSA", 6.00, 1, "Cotizar (estimado)",
     9.99, 2, 0.45, "Amazon", "B0FDKPGXQ4", "La lista del artículo dice 1, pero el ensamble usa 2."),
    ("ROD-02", "Rodamientos", "Rodamiento axial 51107", "35 × 52 × 12 mm", "J2 y J3 (2 por junta)",
     "HTM", 4, "Obligatorio", "CEROSA / RODASA / REPSA", 5.00, 1, "Cotizar (estimado)",
     10.99, 3, 0.45, "Amazon", "https://www.amazon.com/s?k=51107+thrust+ball+bearing",
     "La lista del artículo pide 2 (solo J2); J3 usa el mismo esquema. Paquete de 3 en Amazon."),
    ("ROD-03", "Rodamientos", "Rodamiento radial 6807-2RS", "35 × 47 × 7 mm (pared delgada)", "J1",
     "HTM", 1, "Obligatorio", "CEROSA / RODASA / REPSA", 5.00, 1, "Cotizar (estimado)",
     7.29, 1, 0.1, "Local", "B07RP6RDYL", "No aparece en la lista del artículo, pero el texto lo instala primero en la base."),
    ("ROD-04", "Rodamientos", "Rodamiento radial 6806-2RS (61806)", "30 × 42 × 7 mm (pared delgada)", "J2 y J3",
     "HTM", 2, "Obligatorio", "CEROSA / RODASA / REPSA", 4.50, 1, "Cotizar (estimado)",
     13.99, 10, 0.5, "Local", "B09D33QXFL", "Amazon solo lo vende en paquete de 10."),
    ("ROD-05", "Rodamientos", "Rodamiento 608ZZ", "8 × 22 × 7 mm", "Poleas intermedias de J1 y J2 (2 c/u) + husillo",
     "HTM", 5, "Obligatorio", "CEROSA / REPSA", 1.25, 1, "Estimado (hay en el país)",
     5.19, 10, 0.35, "Local", "B0GYVYQKQ4", ""),
    # Transmisión
    ("TRA-01", "Transmisión", "Correa GT2 cerrada 200 mm", "Ancho 6 mm, paso 2 mm", "J1 etapa 1 (motor → 80 dientes)",
     "HTM", 1, "Obligatorio", "Creativo 3D", 4.00, 1, "Cotizar (estimado)",
     6.92, 5, 0.1, "Amazon", "B0FRDL4X1Z", ""),
    ("TRA-02", "Transmisión", "Correa GT2 cerrada 300 mm", "Ancho 6 mm, paso 2 mm", "J1 etapa 2 y J2 etapa 2",
     "HTM", 2, "Obligatorio", "Creativo 3D", 4.00, 1, "Cotizar (estimado)",
     8.79, 4, 0.1, "Amazon", "B0CN41SWMZ", ""),
    ("TRA-03", "Transmisión", "Correa GT2 cerrada 400 mm", "Ancho 6 mm, paso 2 mm", "J2 etapa 1 y J3",
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

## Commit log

2026-08-21 docs(research): add build architecture research and BOM
    Compare six candidate architectures (anthropomorphic, SCARA, cartesian CNC,
    polar, delta, commercial kit) against the PBL requirements, with error budget,
    bill of materials and cost estimates.
    Recommends a 3-DOF tabletop SCARA with dual end-effector head, L1=L2=20cm and
    base 22cm from the rose center: that geometry keeps theta2 within [72, 126] deg
    across the whole trajectory and cond(J) below 3.5.
    Key finding: on this configuration 1 deg of joint error amplifies to 8.70 mm of
    trace error, so direct-drive MG996R servos (1-2 deg dead band) alone exhaust the
    error budget. Serial-bus servos with encoders or mechanical reduction are the
    e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
2026-08-21 docs(readme): link build research and resolve open questions
    Add a build section summarising the recommended SCARA geometry and the three
    budget routes, and point the repo structure at the new research document.
    Propose answers for two open items: use e_RMS <= 10% of R_max (13.2 mm) as the
    precision criterion, since the local-radius criterion is unusable (the rose
    passes through the origin, so tolerance collapses to zero); and interpolate in
    cartesian space rather than joint space.
    Add a new open item: confirm the 70 g metal object is ferromagnetic. If it is
    aluminium or copper the electromagnet cannot lift it even though the inductive
    sensor still detects it.
2026-08-24 docs(research): add El Salvador local sourcing guide
    Map every SCARA component to a real Salvadoran supplier with address and
    phone: Casa Rivas (25% student discount), Proserquisa, Electronica 2001,
    Steren, CEROSA for bearings, Prestelectro and Intek for industrial sensors,
    Vidri and Freund for structure, Creativo 3D and Avalon Tech for filament.
    Feetech STS3215 serial-bus servos have no local distributor and NEMA 17 has no
    confirmed local retail, so the imported BOM is not reproducible in country.
    Three substitutions keep the SCARA viable without importing anything: cable
    capstan reduction instead of serial-bus servos (zero backlash, hardware-store
    cable, printed drums), wound coil sensors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
2026-08-24 feat(research): add local-actuator decision tree to sourcing guide
    Casa Rivas most likely stocks NEMA 17 without listing it online, and
    no distributor could be confirmed for STS3215 either way, so a single
    fixed BOM doesn't fit what's actually uncertain. Replace that
    uncertainty with a four-route decision tree gated on what's actually
    on the shelf: STS3215 in stock -> Route A, else NEMA 17 + driver in
    stock -> Route B, else steel cable for a capstan -> Route C, else
    printed gears -> Route D. All four fit the existing budget and none
    require ordering anything from outside the country.
    The result changes the framing of the whole document: Route B (NEMA 17
    with 4:1 capstan reduction, 1/16 micr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
2026-09-06 feat(datos): add digitised reference datasets
    [trayectoria_brazo.csv, trayectoria_rosa_polar v-2.csv, wpd_datasets.csv]
2026-10-06 feat(python): add EEZYbotARM Mk2 trajectory simulation
    [eezy_waypoints_ik.csv]
2026-10-06 feat(cad): add HowToMechatronics SCARA reference model
    [Arduino Mega case p2.STL, Arduino Mega case.STL, Arduino UNO case p1.SLDPRT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]
2026-10-06 feat(python): add SCARA kinematic model and report figures
    [scara_waypoints.csv]
2026-10-06 docs: add head BOM and document the SCARA simulation in README
2026-10-06 fix(modelo): limit Z travel by the J2 motor and attach the top cover to the plate
2026-10-06 feat(simulador): move controls to floating panels and tab the data panel
    Design and view controls live in toggleable floating cards (D/V keys); the data panel is collapsible (P) with Movimiento, Graficas, Piezas and Materiales tabs plus a part search. Also fixes the Z column: the top cover now hangs from the top plate disc, the platform is flipped with its closed face up, and Z travel stops before the J2 NEMA hits the top cover (option for the 24 mm NEMA).
2026-10-06 docs: update minimum Z rod lengths for the J2 motor clearance
2026-10-07 feat(presupuesto): add project budget workbook with local and Amazon pricing
    [MathBot_Presupuesto_SCARA.xlsx]
2026-10-07 feat(firmware): add Arduino Mega firmware, test sketches, wiring diagram and Wokwi circuit
2026-10-07 chore(presupuesto): update budget workbook and add the material list without printed parts
    [MathBot_Presupuesto_SCARA.xlsx, lista_materiales_scara_sin_3d_sin_fuente_madera_abrazaderas.xlsx]
2026-10-08 docs(presupuesto): add bearing location diagram cross-checked with HowToMechatronics
2026-10-08 fix(materiales): correct 51107 thrust bearing count and complete bearing specs
    [lista_materiales_scara_sin_3d_sin_fuente_madera_abrazaderas.xlsx]
2026-10-08 fix(simulador): update head pins to the Mega and bearing counts, fix spelling
2026-10-13 feat(firmware): add minimal NEMA stepper test sketch
2026-10-18 feat(anatomia): add interactive isometric figures for NEMA 17, Mega pin map and LM10UU Z axis
    Built with the Anatomy skill: two NEMA 17 variants stepping at 1/4 microstep, Arduino MEGA 2560 + CNC Shield V3 pin functions, and the Z column on four LM10UU bearings. Each figure has a build script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
2026-10-19 feat(simulador): add magnet-only mission mode to run just the electromagnet pickup phase
2026-10-19 feat(simulador): include inductive sensor detection in the magnet-only mission mode
2026-10-20 feat(cabezal): trefoil disc head v2 with exploded view, spring pen lift and tools moved to 55 mm to clear the J3 coupler
2026-10-20 feat(anatomia): add Fig 4 disc head v2 exploded view and Fig 5 lever limit switch homing
2026-10-20 feat(firmware): let prueba_nema move any combination of motors at once
2026-10-24 feat(cabezal): add printable CAD for the trefoil disc head v3
2026-10-24 feat(firmware): match J3 homing, limits and Z heights to the v3 disc head
2026-10-24 feat(simulador): add the v3 flange spacer, measured drop and moved bin
2026-10-24 chore(presupuesto): sync disc head printed parts, spring and rod lengths
2026-10-24 docs(readme): update Z rod lengths and point to the disc head CAD
2026-10-25 feat(cabezal): export assembly meshes and metadata for the panel
2026-10-25 docs: document firmware stages, protocol, panel and console design
2026-10-25 perf(panel): render on demand and cut GPU memory
2026-10-27 feat(anatomia): add handmade electromagnet figure (pot and bolt variants)
2026-10-31 fix(presupuesto): use CAD bolt lengths and itemize hardware
    - J1 pulley uses 4 x M4x60 and J2 pulley 4 x M4x50 (per the SCARA CAD),
    replacing the single M4x55 line
    - Add M2 screws for the limit switches and spell out the estimated
    small screws covered by the assortment
    - Keep the CNC Shield marked as already owned when regenerating
    - Simulator: J1 coupler text now says M4x60
2026-10-31 fix(presupuesto): list the Mega 2560, head pins, M5x25 bolts and panel controls
2026-10-31 fix(simulador): update head A parts and BOM to the v3 hardware
2026-11-02 feat(cabezal): switch the head to the LJ18A3-8-Z/BX M18 sensor
2026-11-02 fix(firmware): set the 40 mm sensor depth and LJ18A3 labels
2026-11-02 fix(panel): use the 40 mm sensor depth and the new head meshes
2026-11-02 fix(simulador): model the LJ18A3 sensor and M18 clamp in the head A BOM
2026-11-02 fix(presupuesto): buy the LJ18A3 at Casa Rivas and add the M3x25 clamp screw
2026-11-02 docs: update the head figure and research pages to the LJ18A3 sensor
2026-11-03 docs(presupuesto): mark the Vidri screw purchase in the screw list
2026-11-03 feat(cabezal): export the printed parts as 3MF for Orca
    CadQuery's 3MF exporter repeats the vertices of every triangle, so Orca reads the mesh as open. Write a closed indexed mesh in millimeters named after each part.
2026-11-03 docs(presupuesto): mark the Proyectos Industriales screw purchase in the screw list
    Claude-Session: https://claude.ai/code/session_0172GwS4v2JN7NiqaVnLV5YN
2026-11-04 feat(poleas): export the printed GT2 pulleys as 3MF for Orca
    Turn the six HTM pulley STLs from Y-up to their largest flat face on the bed and write closed indexed meshes. The 20-tooth motor pulley file holds its three copies in a row.
2026-11-04 feat(firmware): add guided inductive sensor test sketch
    Six steps behind 'a': rest, detection, distance with shims, the four mission parts at 3 mm, noise with the magnet and servo, and bounce. Each prints BIEN or FALLA with what to check.
2026-11-04 feat(firmware): add guided 9-step checklist to the head test
    'x' walks through the J3 endstop, homing, alignment (computes home3), clearance sweep, tool positions, pen lift, magnet grip, sensor and noise while J3 turns, then prints the CFG lines to copy.
2026-11-04 docs(firmware): add visual guide for sensor wiring and head tests
    Wiring through the PC817, sensor mounting at 40 mm, servo calibration and the head checklist, linked from the firmware README.
2026-11-04 feat(cabezal): add 3D step-by-step assembly viewer with fasteners
2026-11-04 chore(launch): add preview server for the assembly viewer
2026-11-04 fix(panel): rotate J3 coupler and connector to match the head bolts
2026-11-06 feat(matlab): add avance 2 virtual prototype with Simscape model of the black SCARA
2026-11-06 feat(matlab): add interactive SCARA app with jog, kinematics and mission playback
2026-11-06 docs(firmware): add electrical drawings for wiring, circuit and inductive sensor
    Three sheets in firmware/diagramas_electricos/index.html: general connection (E-01), block-level circuit schematic (E-02) and LJ18A3 + PC817 wiring to D22 (E-03). Linked from firmware/README.md.
2026-11-06 feat(panel): add joint jog mode for prueba_nema
    prueba_nema gains a non-blocking jog (+N/-N with 400 ms watchdog, stop, zero, release, position report) alongside the half-turn test. The panel detects it and shows a PRUEBA NEMA strip with test buttons, hold-to-jog per joint, keyboard shortcuts and speed presets.
    Also fixes the serial reader spinning forever after close, which froze the page.
2026-11-06 feat(firmware): add dry-run, stop-button and limit-switch switches to mathbot_mega
    CFG seco 1 runs the rosa and the mission with J1-J3 only: Z stays put and
    the pen servo is skipped. CFG hongo 0 ignores D28 while the stop button is
    not wired, and CFG finales 0 reports the unwired limit switches as open.
2026-11-06 feat(panel): add dry-run rosa switch and fix the prueba_nema layout
    The ROSA module gets an EN SECO toggle (CFG seco) and Ajustes lists seco and
    hongo. The prueba_nema controls move to their own MOVER module, and the body
    class is now modo-nema so the .nema rule no longer turns the page into a
    flexbox that broke the layout and scrolling.
2026-11-06 feat(panel): resizable control column and collapsible terminal
    Drag the splitter between the screen and the control column (or use the
    arrow keys on it) to widen the controls; past 860 px the modules flow into
    two columns. The terminal can be resized from its top edge and folded with
    OCULTAR or F2. Sizes and the folded state are remembered per browser;
    double click a splitter to restore the default.
2026-11-10 feat(firmware): add automatic driver standby to mathbot_mega
    CFG reposo n turns the drivers off after n seconds without commands or
    motion so the motors stop humming and heating. The next motion command
    turns them back on; J1-J3 keep their count, and outside dry-run mode Z
    loses its home because it can sag. The status line gains a standby flag
    that the panel shows as an amber MOTORES lamp and a reposo tag, and the
    setting is listed in Ajustes.
